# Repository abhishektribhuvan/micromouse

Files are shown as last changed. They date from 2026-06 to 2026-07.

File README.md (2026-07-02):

# Micromouse Maze Solver Bot






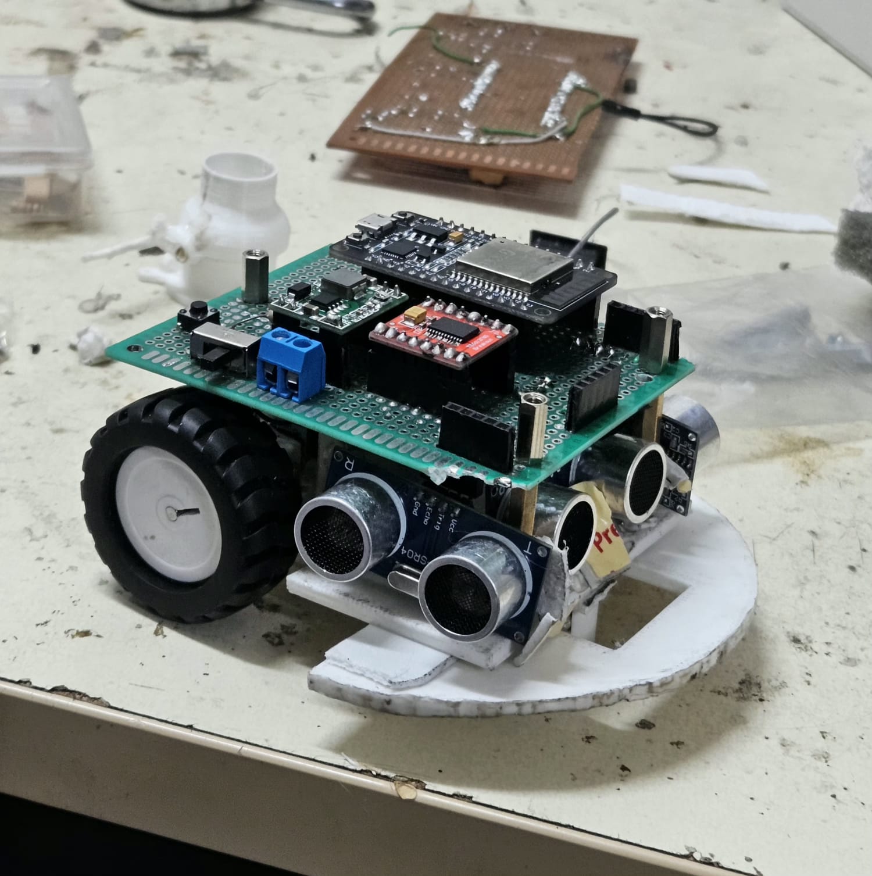
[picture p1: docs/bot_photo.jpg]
Maze Solver Bot
 

This repository contains the complete codebase, 3D chassis design, and hardware documentation to build a fully autonomous Micromouse maze-solving robot. Built on an **ESP32** utilizing **C++** and **PlatformIO**, this project implements complex embedded systems concepts including custom **PID control algorithms**, hardware interrupt-based encoder reading, and real-time state machine logic. 

The robot autonomously maps an unknown maze utilizing the **Flood Fill algorithm**, dynamically calculates the optimal path, and executes a precision high-speed run to the center goal.

##  Key Features & Technical Highlights
* **Dynamic Pathfinding (Graph Theory & DP):** Uses the Flood Fill algorithm to dynamically calculate the **shortest path**. It treats the maze as a grid graph and uses Dynamic Programming principles to update path weights in real-time as new walls are discovered.
* **Highly Efficient Edge Computing:** The pathfinding and mapping algorithms are heavily optimized to run locally on the ESP32 (an edge device), ensuring zero lag between sensor inputs, path recalculations, and motor control.
* **Proportional-Integral-Derivative (PID) Control:** Uses a custom-tuned PID control loop to automatically adjust motor speeds, keeping the robot perfectly centered between maze walls at high speeds.
* **Hardware Interrupts for Precision Odometry:** Uses fast hardware interrupts to read wheel encoders, ensuring the robot turns exactly 90°/180° and moves cell-by-cell with extreme accuracy.
* **Robust State Machine:** Uses a Finite State Machine (FSM) to smoothly transition the robot from mapping the maze (Exploration Mode) to racing to the center (Speed Run Mode).

##  How the Software Works
The robot's brain works in a continuous 3-step loop: **Look, Think, and Move**.

1. **Look (Sense):** The robot checks its surroundings. It uses 3 ultrasonic sensors to "see" walls and rotary encoders on the wheels to track exactly how far it has traveled.
2. **Think (Plan):** The robot updates its internal map with newly discovered walls. It then runs the **Flood Fill algorithm** to calculate the shortest path to the center of the maze.
3. **Move (Act):** The robot drives forward or turns based on its plan. While driving straight, a **PID controller** makes tiny, automatic speed adjustments to both wheels to keep the robot perfectly centered and prevent wall collisions.

##  Repository Structure
- `/src` - The main C++ source code (PlatformIO / Arduino compatible).
- `/hardware` - 3D print `.stl` files for the chassis.
  - [Download Chassis STL](hardware/chassis.stl)
- `/docs` - Documentation, including demo videos and photos.
  - [Watch Demo Video](https://www.youtube.com/shorts/B2bcqpg_jws)

---

## Components List
To build this robot, you will need the following components:
1. **Microcontroller:** ESP32 Development Board (ESP32 DOIT DevKit V1)
2. **Motor Driver:** TB6612FNG Motor Driver Module
3. **Motors:** 2x N20 DC Gear Motors(150 RPM preferred) with built-in quadrature encoders
4. **Sensors:** 3x HC-SR04 Ultrasonic Sensors (Front, Left, Right)
5. **Chassis:** 3D Printed Chassis (see `/hardware/chassis.stl`)
6. **buck converter:** Mini 360 DC-DC Buck Converter
7. **Power:** 2x 18650 Li-ion Batteries (7.4V) and Battery Holder
8. **pcb:** 8cmx12cm Perfboard
9. **wheels:** 4.4x2 cm rubbered wheels for high grip and 1 castel wheel
10. **Misc:** 1x Push Button, 1x 10k Resistor (for button pull-down), Jumper wires, pins for holding components on pcb, Breadboard/PCB(optional).

---

## 🔌 Hardware Connections (Pinout)

Ensure your components are wired to the ESP32 according to this table , you can make the pcb as per your need.

| Component | Pin Function | ESP32 Pin |
| :--- | :--- | :--- |
| **Push Button** | Start/Mode Button | `GPIO 34` (Use external 10k pull-down) |
| **Front Sonar** | Trig / Echo | `GPIO 14` / `GPIO 27` |
| **Left Sonar** | Trig / Echo | `GPIO 33` / `GPIO 32` |
| **Right Sonar** | Trig / Echo | `GPIO 25` / `GPIO 26` |
| **Motor Driver** | ENA (Left PWM) | `GPIO 23` |
| | IN1 / IN2 (Left Dir) | `GPIO 5` / `GPIO 22` |
| | ENB (Right PWM) | `GPIO 18` |
| | IN3 / IN4 (Right Dir) | `GPIO 21` / `GPIO 19` |
| **Left Motor** | Encoder A (Interrupt) | `GPIO 13` |
| **Right Motor** | Encoder A (Interrupt) | `GPIO 4` |

---

##  Step-by-Step Build Guide

### Step 1: 3D Print the Chassis
Navigate to the `hardware/` folder and use your slicer software to print the `chassis.stl` file. PLA or PETG works perfectly.

### Step 2: Mount the Hardware
1. Attach the two DC gear motors with encoders to the bottom of the chassis.
2. Mount the 3 Ultrasonic sensors (Front, Left, Right) to the front brackets of the chassis.
3. Secure the ESP32 and the  motor driver onto the top deck.
4. Add the battery pack at the rear for optimal weight distribution.

### Step 3: Wire the Electronics
Follow the Pinout table above. Ensure that the ground of the motor driver is tied together with the ESP32 ground. Connect the battery directly to the motor driver's motor power input (VMOT/12V), and route the Buck Converter output to power the ESP32 with a clean 5V (via the 5V/VIN pin).

### Step 4: Flash the Code
1. Open this folder in VS Code with the **PlatformIO** extension installed, you can also use the Arduino IDE. for Arduino IDE select the correct board and port from the tools menu. Don't forget to install Esp32 core for Arduino IDE, from the boards manager, esp32 by Espressif systems.

2. The `platformio.ini` is already configured for the ESP32 with `monitor_speed = 115200`.
3. Connect your ESP32 via USB and click **Upload**.

### Step 5: Test and Run
1. Place the robot in the starting square `(0,0)` facing North.
2. Turn on the power.
3. Press the Start Button (Pin 34). The robot will wait 1 second and then begin its **Exploration Run**.
4. Once it reaches the goal, it will stop. Press the button again to execute the **Speed Run**.

---

##  Practical Tuning Guide

Achieving a perfect maze run requires precise tuning of your robot's physical constants. Here is how to calibrate the vital parameters in `main.cpp`.

### 1. How to Calculate Encoder Pulses for Your Motors

In the code, the robot moves forward one cell using the variable `countsPerCell`. To find this exact number, use the following math:

**Formula:**
1. Find your **Wheel Circumference (C)**: `C = Diameter * 3.14159`
2. Find your **Distance Per Count**: `Dist_Per_Count = C / Motor_CPR (Counts Per Revolution)`
3. Calculate **Counts Per Cell**: `Counts = Target_Distance / Dist_Per_Count`

**Example calculation:**
* **Wheel diameter:** 3.4 cm (Circumference = 10.68 cm)
* **Motor CPR:** 120 pulses per revolution of the wheel shaft.
* **Distance Per Count:** `10.68 / 120 = 0.089 cm per count`
* **Standard Maze Cell:** 18.0 cm (Target Distance)
* **Resulting `countsPerCell`:** `18.0 / 0.089 = 202 counts`.

> ** Pro Tip:** Theoretical math gets you close, but tire slip changes things. Set `countsPerCell = 202`, let the robot drive one cell, and measure. If it drives 17cm, increase the counts slightly.

### 2. How to Tune 90° and 180° Turns

The variable `countsFor90DegTurn` determines how long the wheels spin in opposite directions to rotate the chassis in place. 

**Theoretical Formula:**
1. Measure your robot's **Track Width (W)** (the distance between the center of the left and right wheels).
2. The robot turns in a circle with diameter W. The **Turn Circumference** is `W * 3.14159`.
3. A 90-degree turn is exactly 1/4th of that circumference: `Arc_Distance = Turn_Circumference / 4`.
4. **`countsFor90DegTurn`** = `Arc_Distance / Dist_Per_Count`.

**How to Practically Tune It:**
No theoretical calculation will be 100% perfect for turning because wheels drag sideways when pivoting.
1. **Start with the theoretical math.** (e.g., if track width is 8.5cm, 90° arc is ~6.6cm. `6.6 / 0.089 = 74 counts`).
2. **Write a test script:** Modify your `loop()` to simply call `turnRight90(); delay(2000);` endlessly.
3. **Observe and Adjust:** Place the robot on a tile line. If it over-rotates (e.g. 95 degrees), reduce `countsFor90DegTurn` by 2-3 counts. If it under-rotates, increase it.
4. **The 180° Turn:** The code handles 180-degree turns by simply doubling the 90-degree counts (`countsFor90DegTurn * 2`). As long as your 90-degree turn is perfectly calibrated, the 180-degree turn will work flawlessly!
5. **Momentum matters:** If your robot jerks and overshoots after stopping, keep the `delay(50)` after the `stopMotor()` command in the turning functions to allow momentum to settle before taking new sensor readings.

all the best

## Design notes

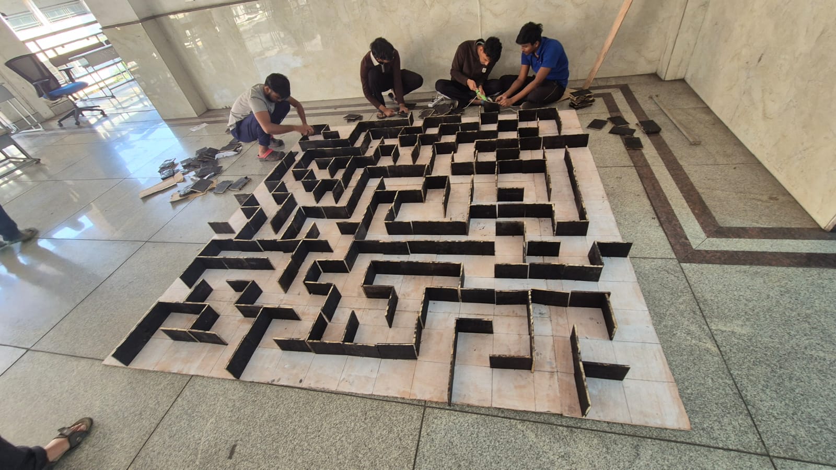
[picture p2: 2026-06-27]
docs/map.jpg

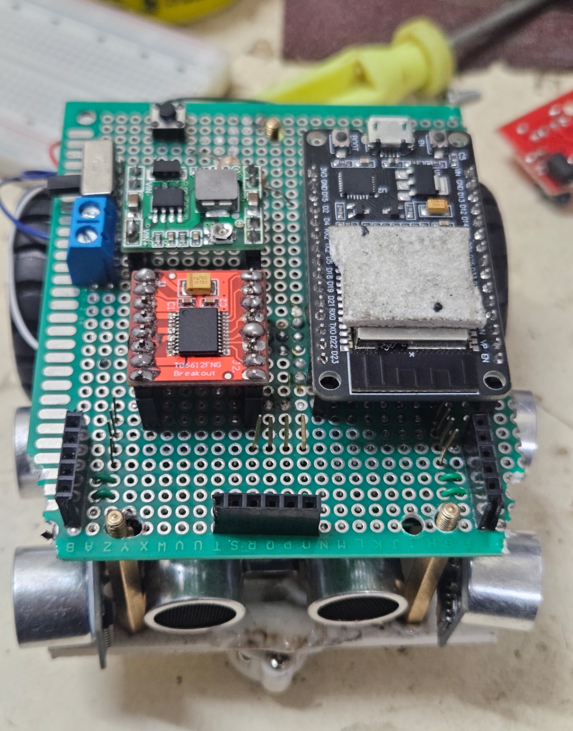
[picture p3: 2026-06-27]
docs/bot-pic2.jpg

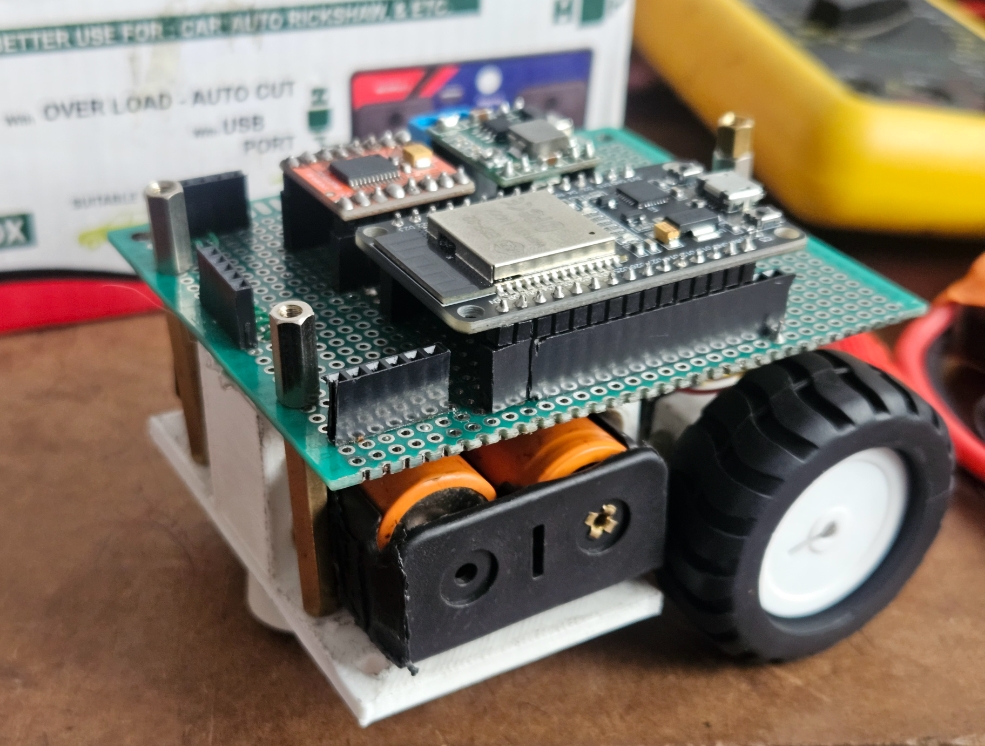
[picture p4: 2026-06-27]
docs/bot_side_view.jpg

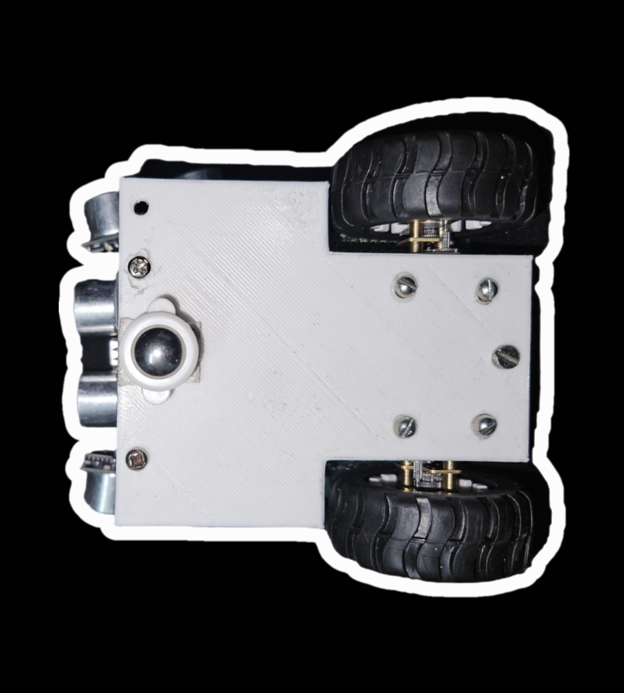
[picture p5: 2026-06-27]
docs/bot_down_side.jpg

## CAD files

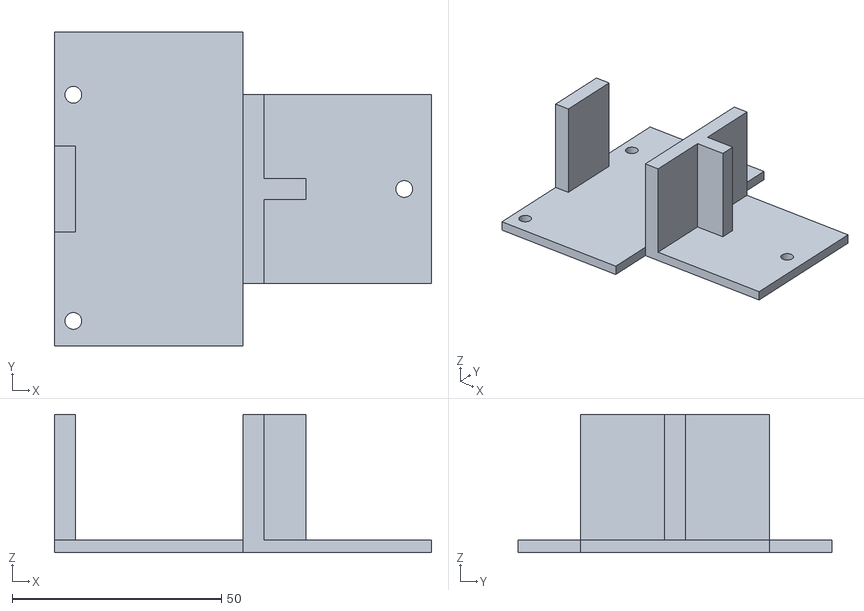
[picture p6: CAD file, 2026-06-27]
hardware/chassis.STL
90.0 x 75.0 x 33.0

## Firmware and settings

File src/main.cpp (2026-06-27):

#include <Arduino.h>

//Micromouse Maze Solver - Flood Fill Algorithm

#define MAZE_WIDTH 4
#define MAZE_HEIGHT 4
#define GOAL_X 3
#define GOAL_Y 0

enum RunState { WAITING_TO_START, EXPLORATION_RUN, SPEED_RUN };
RunState currentState = WAITING_TO_START;
bool pathSaved = false;

int robotX = 0;
int robotY = 0;
enum Direction { NORTH, EAST, SOUTH, WEST };
Direction robotDir = NORTH;

#define BUTTON_PIN  34
#define TRIG_FRONT  14
#define ECHO_FRONT  27
#define TRIG_LEFT   33
#define ECHO_LEFT   32
#define TRIG_RIGHT  25
#define ECHO_RIGHT  26
#define ENA  23
#define IN1  5
#define IN2  22
#define ENB  18
#define IN3  21
#define IN4  19
#define ENC_LEFT   13
#define ENC_RIGHT  4

float Kp = 5.00, Ki = 0, Kd = 0;
float error = 0, lastError = 0, integral = 0;

int baseSpeed = 130;
int explorationSpeed = 130;
int speedRunSpeed = 150;

int currentTurnSpeed = 100;
int explorationTurnSpeed = 100;
int speedRunTurnSpeed = 100;

const long countsPerCell = 900;
const long countsFor90DegTurn = 300;

bool justTurned = false;
const long postTurnOffsetCounts = 70; 
const long centerOffsetCounts = 100;

const float WALL_THRESHOLD_FRONT = 14.0;
const float WALL_THRESHOLD_SIDE = 14.0;
const float TARGET_SIDE_DISTANCE = 4;

unsigned long leftWallDetectTime = 0;
unsigned long rightWallDetectTime = 0;
bool leftWallValid = false;
bool rightWallValid = false;
const int WALL_DEBOUNCE_MS = 150;

volatile long leftCount = 0;
volatile long rightCount = 0;
int maze[MAZE_WIDTH][MAZE_HEIGHT];
uint8_t walls[MAZE_WIDTH][MAZE_HEIGHT] = {0};
#define NORTH_WALL 0b0001
#define EAST_WALL  0b0010
#define SOUTH_WALL 0b0100
#define WEST_WALL  0b1000

void IRAM_ATTR leftEncoderISR() { leftCount++; }
void IRAM_ATTR rightEncoderISR() { rightCount++; }

void setup();
void loop();
float getDistance(int trigPin, int echoPin);
void setMotor(int leftSpeed, int rightSpeed);
void stopMotor();
void resetEncoders();
void resetPID();
void turnRight90();
void turnLeft90();
void turnAround180();
void moveForwardOneCell();
void initializeMaze();
void printMaze();
void updateWalls();
void floodFill();

void setup() {
  Serial.begin(115200);

  pinMode(BUTTON_PIN, INPUT);
  pinMode(TRIG_FRONT, OUTPUT); pinMode(ECHO_FRONT, INPUT);
  pinMode(TRIG_LEFT, OUTPUT);  pinMode(ECHO_LEFT, INPUT);
  pinMode(TRIG_RIGHT, OUTPUT); pinMode(ECHO_RIGHT, INPUT);
  pinMode(IN1, OUTPUT); pinMode(IN2, OUTPUT);
  pinMode(IN3, OUTPUT); pinMode(IN4, OUTPUT);
  pinMode(ENA, OUTPUT); pinMode(ENB, OUTPUT);
  pinMode(ENC_LEFT, INPUT_PULLUP); pinMode(ENC_RIGHT, INPUT_PULLUP);

  attachInterrupt(digitalPinToInterrupt(ENC_LEFT), leftEncoderISR, RISING);
  attachInterrupt(digitalPinToInterrupt(ENC_RIGHT), rightEncoderISR, RISING);

  Serial.println("\nMicromouse Initialized!");
  
  initializeMaze();
  
  Serial.println("Waiting for Button Press to start...");
}

void loop() {
  
  if (currentState == WAITING_TO_START) {
    if (digitalRead(BUTTON_PIN) == HIGH) { 
      delay(50);
      while(digitalRead(BUTTON_PIN) == HIGH);
      
      Serial.println("Button Pressed! Starting in 1 second...");
      delay(1000);
      
      if (!pathSaved) {
        currentState = EXPLORATION_RUN;
        baseSpeed = explorationSpeed;
        currentTurnSpeed = explorationTurnSpeed;
        
        Serial.println("\n--- STARTING EXPLORATION RUN ---");
        Serial.println("Scanning Starting Cell...");
        updateWalls();
        floodFill(); 
        printMaze();
        delay(500); 
      } else {
        currentState = SPEED_RUN;
        baseSpeed = speedRunSpeed;
        currentTurnSpeed = speedRunTurnSpeed;
        
        robotX = 0;
        robotY = 0;
        robotDir = NORTH;
        justTurned = false;
        
        Serial.println("\n--- STARTING SPEED RUN ---");
        printMaze(); 
        delay(500);
      }
    }
    return;
  }

  if (robotX == GOAL_X && robotY == GOAL_Y) {
    if (currentState == EXPLORATION_RUN) {
      Serial.println("\n**");
      Serial.println("EXPLORATION GOAL REACHED!");
      Serial.println("Path Saved. Place robot back at (0,0).");
      Serial.println("Press the button to begin Speed Run.");
      Serial.println("**");
      stopMotor();
      
      pathSaved = true;
      currentState = WAITING_TO_START;
      return;

    } else if (currentState == SPEED_RUN) {
      Serial.println("\n**");
      Serial.println("SPEED RUN COMPLETE!");
      Serial.println("Press button to run again.");
      Serial.println("*");
      stopMotor();
      
      currentState = WAITING_TO_START;
      return;
    }
  }

  Serial.print("\nNEW CYCLE"); Serial.print(robotX); Serial.print(","); Serial.print(robotY); Serial.println("*");

  int northVal = 1000, eastVal = 1000, southVal = 1000, westVal = 1000;
  if (robotY < MAZE_HEIGHT - 1 && !(walls[robotX][robotY] & NORTH_WALL)) northVal = maze[robotX][robotY + 1];
  if (robotX < MAZE_WIDTH - 1  && !(walls[robotX][robotY] & EAST_WALL))  eastVal  = maze[robotX + 1][robotY];
  if (robotY > 0               && !(walls[robotX][robotY] & SOUTH_WALL)) southVal = maze[robotX][robotY - 1];
  if (robotX > 0               && !(walls[robotX][robotY] & WEST_WALL))  westVal  = maze[robotX - 1][robotY];

  int minVal = min(min(northVal, eastVal), min(southVal, westVal));

  Direction desiredDir;
  if (northVal == minVal) desiredDir = NORTH;
  else if (eastVal == minVal) desiredDir = EAST;
  else if (southVal == minVal) desiredDir = SOUTH;
  else desiredDir = WEST;

  int turns_needed = desiredDir - robotDir;
  if (turns_needed == 1 || turns_needed == -3) turnRight90();
  else if (turns_needed == -1 || turns_needed == 3) turnLeft90();
  else if (turns_needed == 2 || turns_needed == -2) turnAround180();
  
  moveForwardOneCell();

  if (currentState == EXPLORATION_RUN) { 
    Serial.print("Arrived at ("); Serial.print(robotX); Serial.print(","); Serial.print(robotY); Serial.println("). Scanning for walls...");
    updateWalls();
    Serial.println("Recalculating all paths with new info...");
    floodFill();
    printMaze(); 
    delay(500); 
  } else {
    Serial.print("Arrived at ("); Serial.print(robotX); Serial.print(","); Serial.print(robotY); Serial.println(").");
    delay(100); 
  }
}

float getDistance(int trigPin, int echoPin) {
  long readings[5];
  for (int i = 0; i < 5; i++) {
    digitalWrite(trigPin, LOW); delayMicroseconds(2);
    digitalWrite(trigPin, HIGH); delayMicroseconds(10);
    digitalWrite(trigPin, LOW);
    long duration = pulseIn(echoPin, HIGH, 20000);
    float distance = duration * 0.0343 / 2.0;
    readings[i] = (distance == 0 || distance > 40) ? 40 : distance;
    delay(4);
  }
  for (int i = 0; i < 4; i++) { for (int j = i + 1; j < 5; j++) { if (readings[j] < readings[i]) { long temp = readings[i]; readings[i] = readings[j]; readings[j] = temp; } } }
  return readings[2];
}

void setMotor(int leftSpeed, int rightSpeed) {
  leftSpeed = constrain(leftSpeed, -255, 255); rightSpeed = constrain(rightSpeed, -255, 255);
  digitalWrite(IN1, leftSpeed > 0 ? HIGH : LOW); digitalWrite(IN2, leftSpeed > 0 ? LOW : HIGH); analogWrite(ENA, abs(leftSpeed));
  digitalWrite(IN3, rightSpeed > 0 ? HIGH : LOW); digitalWrite(IN4, rightSpeed > 0 ? LOW : HIGH); analogWrite(ENB, abs(rightSpeed));
}
void stopMotor() { setMotor(0, 0); }
void resetEncoders() { leftCount = 0; rightCount = 0; }
void resetPID() { integral = 0; lastError = 0; }

void turnRight90() {
  Serial.println("Action: Turning Right");
  
  resetEncoders(); resetPID();
  while ((abs(leftCount) + abs(rightCount)) / 2 < centerOffsetCounts) { 
    float distFront = getDistance(TRIG_FRONT, ECHO_FRONT);
    if(distFront < 3.0 && distFront > 0.0) {
      break;
    }
    setMotor(currentTurnSpeed, currentTurnSpeed); 
  }
  setMotor(-255, -255); delay(10);
  stopMotor(); delay(50);
  
  resetEncoders(); resetPID();
  while ((abs(leftCount) + abs(rightCount)) / 2 < countsFor90DegTurn) { setMotor(currentTurnSpeed, -currentTurnSpeed); }
  setMotor(-255, 255); delay(15);
  stopMotor();
  robotDir = (Direction)((robotDir + 1) % 4);
  justTurned = true;
}

void turnLeft90() {
  Serial.println("Action: Turning Left");
  
  resetEncoders(); resetPID();
  
  while ((abs(leftCount) + abs(rightCount)) / 2 < centerOffsetCounts ){ 
    float distFront = getDistance(TRIG_FRONT, ECHO_FRONT);
    if(distFront < 3.0 && distFront > 0.0) {
      break;
    }
    setMotor(currentTurnSpeed, currentTurnSpeed); 
  }
  setMotor(-255, -255); delay(10);
  stopMotor(); delay(50);

  resetEncoders(); resetPID();
  while ((abs(leftCount) + abs(rightCount)) / 2 < countsFor90DegTurn) { setMotor(-currentTurnSpeed, currentTurnSpeed); }
  setMotor(255, -255); delay(15);
  stopMotor();
  robotDir = (Direction)((robotDir + 3) % 4);
  justTurned = true;
}

void turnAround180() {
    Serial.println("Action: Turning Around 180 & Aligning");
    
    resetEncoders(); resetPID();
    long target = countsFor90DegTurn * 2;
    while ((abs(leftCount) + abs(rightCount)) / 2 < target) { 
        setMotor(currentTurnSpeed, -currentTurnSpeed); 
    }
    stopMotor();
    delay(100);

    int alignAttempts = 0;
    while (alignAttempts < 20) {
        float dLeft = getDistance(TRIG_LEFT, ECHO_LEFT);
        float dRight = getDistance(TRIG_RIGHT, ECHO_RIGHT);

        if (dLeft > WALL_THRESHOLD_SIDE && dRight > WALL_THRESHOLD_SIDE) {
            break; 
        }

        float diff = dLeft - dRight;
        
        if (abs(diff) <= 1.5) {
            break; 
        }

        if (dLeft < dRight) {
            setMotor(85, -85); 
        } else {
            setMotor(-85, 85); 
        }
        
        delay(35); 
        stopMotor();
        delay(40); 
        
        alignAttempts++;
    }
    
    robotDir = (Direction)((robotDir + 2) % 4);
    justTurned = true; 
}

void moveForwardOneCell() {
  Serial.println("Action: Moving Forward One Cell");
  
  leftWallDetectTime = 0;
  rightWallDetectTime = 0;
  leftWallValid = false;
  rightWallValid = false;
  
  long targetCounts = justTurned ? (countsPerCell - postTurnOffsetCounts) : countsPerCell;
  justTurned = false;
  
  resetEncoders(); resetPID();
  
  while ((abs(leftCount) + abs(rightCount)) / 2 < targetCounts) {
      float distFront = getDistance(TRIG_FRONT, ECHO_FRONT);
      if (distFront < 3.0 && distFront > 0.0) { 
          Serial.println("EMERGENCY STOP: Front wall < 3cm!");
          stopMotor();
          break;
      }

      float distLeft = getDistance(TRIG_LEFT, ECHO_LEFT);
      float distRight = getDistance(TRIG_RIGHT, ECHO_RIGHT);
      
      if (distLeft < WALL_THRESHOLD_SIDE) {
          if (leftWallDetectTime == 0) leftWallDetectTime = millis();
          if (millis() - leftWallDetectTime > WALL_DEBOUNCE_MS) {
              leftWallValid = true;
          }
      } else {
          leftWallDetectTime = 0;
          leftWallValid = false;
      }

      if (distRight < WALL_THRESHOLD_SIDE) {
          if (rightWallDetectTime == 0) rightWallDetectTime = millis();
          if (millis() - rightWallDetectTime > WALL_DEBOUNCE_MS) {
              rightWallValid = true;
          }
      } else {
          rightWallDetectTime = 0;
          rightWallValid = false;
      }
      
      if (leftWallValid && rightWallValid) { error = distLeft - distRight; }
      else if (leftWallValid) { error = 2*(distLeft - TARGET_SIDE_DISTANCE); }
      else if (rightWallValid) { error = 2*(TARGET_SIDE_DISTANCE - distRight); }
      else { error = 0; }
      
      float correction = Kp * error;
      setMotor(constrain(baseSpeed - correction, 0, 255), constrain(baseSpeed + correction, 0, 255));
   
      delay(10);
  }
  stopMotor();
  
  if (robotDir == NORTH) robotY++;
  if (robotDir == EAST)  robotX++;
  if (robotDir == SOUTH) robotY--;
  if (robotDir == WEST)  robotX--;
}

void initializeMaze() {
  for (int y = 0; y < MAZE_HEIGHT; y++) {
    for (int x = 0; x < MAZE_WIDTH; x++) {
      maze[x][y] = abs(x - GOAL_X) + abs(y - GOAL_Y);
    }
  }
}

void printMaze() {
    Serial.println("\n--- ROBOT'S CURRENT MAP ---");
    for (int y = MAZE_HEIGHT - 1; y >= 0; y--) {
        for (int x = 0; x < MAZE_WIDTH; x++) {
            Serial.print("+");
            Serial.print((walls[x][y] & NORTH_WALL) ? "---" : "   ");
        }
        Serial.println("+");
        for (int x = 0; x < MAZE_WIDTH; x++) {
            Serial.print((walls[x][y] & WEST_WALL) ? "| " : "  ");
            if (x == robotX && y == robotY) { Serial.print("R"); } 
            else { Serial.print(maze[x][y]); }
            if(maze[x][y] < 10 && !(x == robotX && y == robotY)) Serial.print(" ");
            Serial.print(" ");
        }
        Serial.println("|");
    }
    for (int x = 0; x < MAZE_WIDTH; x++) { Serial.print("+---"); }
    Serial.println("+");
}

void updateWalls() {
    float distFront = getDistance(TRIG_FRONT, ECHO_FRONT);
    float distLeft  = getDistance(TRIG_LEFT, ECHO_LEFT);
    float distRight = getDistance(TRIG_RIGHT, ECHO_RIGHT);

    Serial.print("Sensor Readings: F="); Serial.print(distFront);
    Serial.print(" L="); Serial.print(distLeft);
    Serial.print(" R="); Serial.println(distRight);

    if (distFront < WALL_THRESHOLD_FRONT) {
        if (robotDir == NORTH) walls[robotX][robotY] |= NORTH_WALL;
        if (robotDir == EAST)  walls[robotX][robotY] |= EAST_WALL;
        if (robotDir == SOUTH) walls[robotX][robotY] |= SOUTH_WALL;
        if (robotDir == WEST)  walls[robotX][robotY] |= WEST_WALL;
    }
    if (distLeft < WALL_THRESHOLD_SIDE) {
        if (robotDir == NORTH) walls[robotX][robotY] |= WEST_WALL;
        if (robotDir == EAST)  walls[robotX][robotY] |= NORTH_WALL;
        if (robotDir == SOUTH) walls[robotX][robotY] |= EAST_WALL;
        if (robotDir == WEST)  walls[robotX][robotY] |= SOUTH_WALL;
    }
    if (distRight < WALL_THRESHOLD_SIDE) {
        if (robotDir == NORTH) walls[robotX][robotY] |= EAST_WALL;
        if (robotDir == EAST)  walls[robotX][robotY] |= SOUTH_WALL;
        if (robotDir == SOUTH) walls[robotX][robotY] |= WEST_WALL;
        if (robotDir == WEST)  walls[robotX][robotY] |= NORTH_WALL;
    }

    if ((walls[robotX][robotY] & NORTH_WALL) && (robotY < MAZE_HEIGHT - 1)) walls[robotX][robotY+1] |= SOUTH_WALL;
    if ((walls[robotX][robotY] & EAST_WALL)  && (robotX < MAZE_WIDTH - 1))  walls[robotX+1][robotY] |= WEST_WALL;
    if ((walls[robotX][robotY] & SOUTH_WALL) && (robotY > 0))               walls[robotX][robotY-1] |= NORTH_WALL;
    if ((walls[robotX][robotY] & WEST_WALL)  && (robotX > 0))               walls[robotX-1][robotY] |= EAST_WALL;
}

void floodFill() {
    int queueX[MAZE_WIDTH * MAZE_HEIGHT];
    int queueY[MAZE_WIDTH * MAZE_HEIGHT];
    int head = 0, tail = 0;

    for(int i = 0; i < MAZE_WIDTH; i++) for(int j = 0; j<MAZE_HEIGHT; j++) maze[i][j] = 255;

    queueX[tail] = GOAL_X;
    queueY[tail] = GOAL_Y;
    maze[GOAL_X][GOAL_Y] = 0;
    tail++;

    while (head != tail) {
        int curX = queueX[head]; int curY = queueY[head];
        head++;
        if (curY < MAZE_HEIGHT - 1 && !(walls[curX][curY] & NORTH_WALL) && maze[curX][curY+1] == 255) {
            maze[curX][curY+1] = maze[curX][curY] + 1;
            queueX[tail] = curX; queueY[tail] = curY + 1; tail++;
        }
        if (curX < MAZE_WIDTH - 1 && !(walls[curX][curY] & EAST_WALL) && maze[curX+1][curY] == 255) {
            maze[curX+1][curY] = maze[curX][curY] + 1;
            queueX[tail] = curX + 1; queueY[tail] = curY; tail++;
        }
        if (curY > 0 && !(walls[curX][curY] & SOUTH_WALL) && maze[curX][curY-1] == 255) {
            maze[curX][curY-1] = maze[curX][curY] + 1;
            queueX[tail] = curX; queueY[tail] = curY - 1; tail++;
        }
        if (curX > 0 && !(walls[curX][curY] & WEST_WALL) && maze[curX-1][curY] == 255) {
            maze[curX-1][curY] = maze[curX][curY] + 1;
            queueX[tail] = curX - 1; queueY[tail] = curY; tail++;
        }
    }
}
